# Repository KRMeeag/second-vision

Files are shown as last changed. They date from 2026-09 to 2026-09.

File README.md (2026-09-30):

# **Second Vision: IoT-Based Smart Glasses for the Visually Impaired**

Real-time object detection and depth estimation on edge hardware, delivering spatial awareness through audio and haptic feedback.

---

## What It Does

Second Vision is a head-mounted assistive device that helps visually impaired users navigate their surroundings:

- **🔊 Audio Feedback** — Announces detected objects with spatial position: *"person left"*, *"car center"*, *"bicycle right"*
- **📳 Haptic Feedback** — Three vibration motors (left, center, right) vibrate proportionally to obstacle proximity
- **🧭 Body- and Head-Height Awareness** — Second Vision watches for the things people walk into: walls, doors, furniture, other people, low branches and overhanging signs at torso and head height. It does not sense the ground, so it will **not** warn about stairs, curbs or drop-offs — every wearer is told this before first use.

Object detection identifies *known* objects (people, cars, obstacles). Depth estimation detects *all* obstacles, including those the AI can't classify. 

---

## Hardware

| Component | Spec |
|---|---|
| Compute | Raspberry Pi 5 (8GB RAM) |
| AI Accelerator | Hailo AI Hat+ (Hailo-8, 26 TOPS) |
| Camera | OV2640 USB Camera Module |
| Motor Controller | ESP32 (wired USB serial) |
| Vibration Motors | 3× ERM (left temple, forehead, right temple) |
| Audio | Bone-conduction earphones |
| Control Panel | Arduino (switches, potentiometers, buttons) |
| Power (motors) | 18650 Li-ion cell via MOSFETs |
| OS | Raspberry Pi OS Trixie (64-bit) |

## Software Stack

| Layer | Technology |
|---|---|
| Detection Model | YOLOv8n (Hailo HEF) |
| Depth Model | SC-DepthV3 (Hailo HEF) |
| Inference Runtime | HailoRT + GStreamer |
| Framework | [`hailo_apps`](https://github.com/hailo-ai/hailo-apps) (pip-installed library) |
| TTS | pyttsx3 / espeak-ng |
| Serial Protocol | Binary (RPi5 ↔ ESP32), Text (Arduino → RPi5) |
| Language | Python 3.13 |

---

## Quick Start

### Prerequisites

- Raspberry Pi 5 with Hailo AI Hat+ installed
- `hailo_apps` package installed in virtual environment
- OV2640 camera connected via USB

### Setup

```bash
# Clone the repository
git clone <repo-url>
cd second-vision-repo

# (FOR RPI ONLY) Make sure to have the necessary PyGOBject and GStreamer bindings (required)
sudo apt install python3-gi python3-gi-cairo gir1.2-gtk-4.0

# Install necessary project dependencies
poetry install 

# Create and activate virtual environment
python3 -m venv --system-site-packages my_hailo_env
source my_hailo_env/bin/activate
```

### Run

```bash
# Mock mode (no hardware needed — for development)
./scripts/run.sh --mock

# With camera (display mode for testing)
./scripts/run.sh --input rawusb:///dev/video0 --width 640 --height 360 --frame-rate 25

# Full system (headless, with ESP32 and Arduino)
./scripts/run.sh --input rawusb:///dev/video0 --width 640 --height 360 --frame-rate 25 \
    --serial-port /dev/ttyUSB0 \
    --config-port /dev/ttyACM0 \
    --headless
```

---

## Architecture

```
Camera → Hailo-8 NPU ─┬─→ YOLOv8n (detection) → TTS → Speaker
                       └─→ SC-DepthV3 (depth)  → ESP32 → 3× Motors

Arduino Control Panel → RPi5 → Runtime configuration
```

The system runs a GStreamer pipeline with two parallel inference branches. Each branch has a callback that pushes results into a thread-safe queue. Daemon worker threads consume from the queues and produce outputs (audio, serial commands).

See [`documentation/ARCHITECTURE.md`](documentation/ARCHITECTURE.md) for the full architecture document.

---

## Project Structure

```
second-vision-repo/
├── src/
│   └── second_vision/
│       ├── main.py                ← Entry point
│       ├── pipeline/              ← GStreamer pipeline + callbacks
│       ├── workers/               ← TTS, serial, config reader threads
│       ├── core/                  ← Config, protocol, depth utilities
│       └── mock/                  ← Fake data generators for --mock mode
├── scripts/
│   └── run.sh                     ← Launch script
├── config/                        ← Default settings
├── tests/                         ← Unit tests
├── documentation/                       ← Documentation
│   ├── PROJECT.md                 ← Project overview
│   ├── ARCHITECTURE.md            ← System architecture
│   ├── DECISIONS.md               ← Architectural decisions log
│   ├── PLAN.md                    ← Implementation phases
│   └── TASKS.md                   ← Task breakdown
├── CLAUDE.md                      ← AI agent instructions
└── README.md                      ← You are here

```

---

## Development

### Mock Mode

Run the full system without any hardware. Generates fake detections and depth data for testing workers:

```bash
./scripts/run.sh --mock
```

### Stub Pattern

Every component starts as a working stub. Replace the private functions marked `# STUBS BELOW` with real implementations. The worker loop, queue interface, and config integration never change.

See [`documentation/PLAN.md`](documentation/PLAN.md) for the phased implementation plan.

### Running Tests

```bash
source my_hailo_env/bin/activate
python3 -m pytest tests/
```

---

## Documentation

| Document | Description |
|---|---|
| [`AGENT.md`](AGENT.md) | Instructions for AI coding agents — read this first |
| [`PROJECT.md`](documentation/PROJECT.md) | Project overview, team, hardware specs |
| [`ARCHITECTURE.md`](documentation/ARCHITECTURE.md) | System architecture, data flow, protocols |
| [`DECISIONS.md`](documentation/DECISIONS.md) | All architectural decisions with rationale |
| [`PLAN.md`](documentation/PLAN.md) | 10-phase implementation plan |
| [`TASKS.md`](documentation/TASKS.md) | Granular task checklist |

---

## Researchers

- **Kenzhu Aguilera**
- **Waldric Jude S. Garcia**
- **Kenth Razen M. Magbanua**
- **Reiven O. Jasa**

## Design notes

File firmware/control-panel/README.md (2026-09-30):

# Second Vision — ESP32 Control Panel (PlatformIO)

Firmware for the physical settings panel. Emits the line protocol parsed by
`src/second_vision/workers/config_reader.py`:

    V:panel:<n>        protocol version, boot only
    S:<key>:<value>    setting   e.g. S:motor_strength:0.60
    M:<mode>           pipeline mode: detection | depth | both | none
    B:<name>           event: status | alive

`PROTOCOL.md` is the authoritative contract. Where this README and that file
disagree, PROTOCOL.md wins.

Wiring diagrams:

| File | Covers | Regenerate with |
|---|---|---|
| `docs/breadboard_wiring.svg` | controls → ESP32, on the breadboard | `python3 docs/gen_wiring.py` |
| `docs/pi_link_wiring.svg` | ESP32 → Raspberry Pi 5, over UART | `python3 docs/gen_pi_link.py` |

Edit the board constants at the top of `gen_wiring.py` before re-running it.

## Environments

| Env | File | Use |
|---|---|-----|
| `polarity` | `src/polarity_test.cpp`| Bring-up. Raw pin states + ADC + implied mode. |
| `panel` | `src/control_panel.cpp`| The real firmware. Default env. |
| `bench` | `src/control_panel.cpp`| Same firmware, `-D HAVE_POT=0`. For a bare board with no breadboard — an unfitted pot floats GPIO34 and floods the link. |

### The motor board lives elsewhere

Everything in `src/` is **control-panel** firmware. The glasses /
vibration-motor ESP32 (XIAO ESP32-C3, binary, 115200, bidirectional, driven
by `--serial-port` rather than `--config-port`) has its own PlatformIO
project in `firmware/esp32_haptic_feedback/`. The old `motorlink` link-check
sketch that used to sit here as `src/main.cpp` is gone; that board's
protocol is exercised by `scripts/test_motor_packet.py` and
`tests/test_serial_worker.py` instead.

`PROTOCOL.md` documents the **panel** protocol only.

    pio run -e polarity -t upload -t monitor
    pio run -e panel    -t upload -t monitor
    pio run -e bench    -t upload -t monitor    # laptop, no breadboard

Upload is 115200: this DevKit fails at both 921600 and 460800 once esptool
switches to the high rate for the stub. Hold IO0 for the ENTIRE upload — the
auto-reset is unreliable.

## Controls

Two latching rockers, one per capability. Each owns a model **and** the output
channel that model feeds — a model with no route to the user is just heat.

| Rocker | Model | Output channel |
|---|---|---|
| `DETECT` | YOLOv8 object detection| speech (`tts_enabled`) |
| `DEPTH`  | SC-DepthV3 depth | motors (`vibration_enabled`)|

The pair *is* the pipeline mode — there is no separate mode control, so the
panel can never show a position that is not what is running:

| DETECT | DEPTH | emitted |
|---|---|---|
| on | on | `M:both` |
| on | off | `M:detection` |
| off | on | `M:depth` |
| off | off | `M:none` |

`M:none` means **run nothing** — not "run both and mute". A model with no route
to the user is wasted Hailo time and battery. `app.py` has a matching
`MODE_NONE` with an idle pipeline builder that keeps the camera running but
detaches both inference branches, so flipping a rocker back is near-instant
rather than paying a camera cold-start on top of the rebuild blackout.

## Pin map

| Control | Pin | Notes |
|---|---|---|
| DETECT rocker  | GPIO17  | latching, INPUT_PULLUP, active LOW |
| DEPTH rocker | GPIO18  | latching, INPUT_PULLUP, active LOW |
| Status button  | GPIO22  | momentary, active LOW |
| B10K pot | GPIO34  | ADC1, input-only, no pull-up |

GPIO19 and GPIO21 are free — the mode button and KY-004 are gone. Both wrote
settings the rockers now own, and two controls writing one setting is how a
panel ends up lying about its state.

**GPIO23 carries the Pi link wire** (UART2 TX) and is not free.

**Both rocker pins are chosen so a mis-plugged jumper cannot short the supply.**
GPIO17 and GPIO18 have plain GPIOs on either side (GPIO5/GPIO16 and
GPIO19/GPIO5), so a wire one hole off reads wrong rather than drawing current.
GPIO23 takes no *switch*: it is one row from the GND pin, on a row carrying 3V3
on the opposite side of the board, so a one-hole slip is a dead short across the
regulator — a hot module and garbage on every pin at once. A single soldered
link wire is acceptable there; a switch leg, which can bridge two rows, is not.

## Shared power, and the heartbeat

Panel and Pi are powered together by the X1202, so they boot together and the
Pi is ~30 s from opening the port. A one-shot report at boot would be lost,
leaving `SystemConfig` disagreeing with switches the user can see and feel.

So `control_panel.cpp` emits `B:alive` and then re-announces its whole state
every `HEARTBEAT_MS` (10 s), forever. That survives the boot race, a dropped
byte, and any restart of `main.py` while the panel stays powered — the common
case in development.

This is only safe because `config_reader.py` acts on **changes**: an
unconditional reader would call `trigger_rebuild()` on every heartbeat and tear
the Hailo pipeline down every 10 seconds. If you ever touch either side, that
invariant is the one to preserve.

## Serial

9600 baud, to match `_open_config_port()` on the Pi. The ESP32's ROM boot log
is 115200, so a burst of garbage on reset is expected and harmless.

At runtime the panel reaches the Pi over the GPIO UART, not USB — USB is only
for flashing, because the GPIO UART has no DTR/RTS to drive the bootloader.
Three wires, `docs/pi_link_wiring.svg`:

    X1202 5V     ->  ESP32 5V pin               power (XH2.54 header)
    X1202 GND    ->  ESP32 GND                  also the Pi's ground
    ESP32 GPIO23 ->  Pi pin 21  (GPIO9, uart3-pi5 RX)   NOT pin 10

**The link is pin 21, not pin 10.** The primary UART (`/dev/serial0`, pins
6/8/10) belongs to the motor-controller ESP32-C3 — verified by reading that
port, which carries its ROM banner. The panel gets a second UART instead:
`dtoverlay=uart3-pi5` in `config.txt`, GPIO8/GPIO9 on pins 24/21. GPIO9 is also
SPI0 MISO, so it is free only while `dtparam=spi` stays off.

**And the ESP32 end is GPIO23, not GPIO1.** GPIO1 is UART0 TX — the USB serial — and the
ROM bootloader dumps its 115200 log there on every reset, which would land
straight in `config_reader.py`. GPIO23 is UART2: the Pi never sees that garbage,
and USB stays usable for flashing and monitoring at the same time.

Power comes from the Geekworm X1202 UPS, not the Pi's header. The ESP32's own
`3V3` pin still feeds the breadboard `+` rail — the X1202's 5 V goes to the 5V
pin and nowhere else, so the pot keeps a safe 3.3 V reference. Because the X1202
feeds the Pi, its GND and the Pi's GND are one node — grounding the ESP32 there
already references it to the Pi, so only the signal wire touches the 40-pin
header. Unplug the 5 V feed before flashing over USB.

**Pin name depends on the board.** The 38-pin DevKit used here labels its 5 V
input `5V`; 30-pin boards label the same pin `VIN`. They are the regulator
input either way — never the `3V3` pin, which bypasses the regulator and puts
5 V straight on the module.

The Pi's serial login console was removed from `cmdline.txt` and
`enable_uart=1` added to `config.txt`. `/dev/serial0` (→ `ttyAMA0`) is the
**motor** link; `dtoverlay=uart3-pi5` adds the panel's own UART on GPIO8/9.

Confirm the device name after rebooting — Pi 5 numbering is not Pi 4's:

    ls -l /dev/ttyAMA*

then run the pipeline with `--config-port /dev/ttyAMA<n>` for whichever node
`uart3-pi5` created. Do **not** assume it; the primary already moved from
`ttyAMA10` to `ttyAMA0` once across a reboot in this project.

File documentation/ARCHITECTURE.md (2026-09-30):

# ARCHITECTURE.md — System Architecture

> **Last synced: 2026-07-27.** Verified against source.
> This is the single source of truth for how the system is built.
>
> The depth post-processing section is deliberately kept high-level: that design is still
> moving. See [PLAN.md](PLAN.md#2-depth-estimation-callbacks).

---

## System Overview

```
┌─────────────────────────────────────────────────────────────────┐
│                     HEAD-MOUNTED UNIT                           │
│  [Camera]  [Motor L]  [Motor C]  [Motor R]  [Earpiece]         │
└──────┬────────┬──────────┬──────────┬───────────┬───────────────┘
       │        │          │          │           │
  USB  │   ┌────┴──────────┴──────────┴────┐     │ audio
       │   │          ESP32                 │     │
       │   │  3× MOSFET PWM + 18650 power  │     │
       │   └──────────────┬────────────────┘     │
       │             USB Serial                   │
       │                  │                       │
┌──────┴──────────────────┴───────────────────────┴───────────────┐
│                    RASPBERRY PI 5                                │
│                                                                 │
│  ┌──────────────────────────────────────────────────────────┐   │
│  │              GStreamer Pipeline (Hailo-8 NPU)             │   │
│  │                                                          │   │
│  │  Camera → tee ──→ SCDepthV3 ──→ depth_callback           │   │
│  │               └──→ YOLOv8n ──→ tracker ──→ det_callback  │   │
│  └──────────────────────────────────────────────────────────┘   │
│           │                              │                      │
│     serial_queue                   tts_queue                    │
│     (queue.Queue)                  (queue.Queue)                │
│           │                              │                      │
│  ┌────────▼────────┐          ┌──────────▼──────────┐          │
│  │  Serial Worker   │          │    TTS Worker        │          │
│  │  (daemon thread) │          │   (daemon thread)    │          │
│  │  binary protocol │          │   espeak-ng + cooldown│          │
│  └────────┬─────────┘          └──────────┬──────────┘          │
│           │                               │                     │
│      USB Serial                      espeak-ng                  │
│      to ESP32                        subprocess                 │
│                                                                 │
│  ┌──────────────────┐     ┌─────────────────┐                  │
│  │  Config Reader    │     │  SystemConfig    │                  │
│  │  (daemon thread)  │────→│  (thread-safe)   │                  │
│  │  Arduino serial   │     │  shared state    │                  │
│  └────────┬──────────┘     └────────┬────────┘                  │
│           │                         │ read by all workers       │
│      USB Serial                     │                           │
└───────────┼─────────────────────────┼───────────────────────────┘
            │                         
┌───────────┴──────────┐              
│   Arduino Control     │              
│   Panel (switches,    │              
│   pots, buttons)      │              
└──────────────────────┘              
```

---

## Threading Model

| # | Thread | Type | Input | Output | Lifetime |
|---|---|---|---|---|---|
| 1 | GLib MainLoop | Main thread | GStreamer bus events | Pipeline state mgmt | App lifetime |
| 2 | Depth streaming | GStreamer-managed | Camera frames | SCDepthV3 inference → depth_callback | While depth pipeline active |
| 3 | Det streaming | GStreamer-managed | Camera frames | YOLOv8 inference → det_callback | While det pipeline active |
| 4 | TTS Worker | `threading.Thread` daemon | `tts_queue` | espeak-ng audio | App lifetime |
| 5 | Serial Writer | `threading.Thread` daemon | `serial_queue` | Binary packets to ESP32 | App lifetime |
| 6 | Config Reader | `threading.Thread` daemon | Arduino serial text | `SystemConfig` updates | App lifetime |
| 7 | *(opt)* Watchdog | `threading.Thread` daemon | Frame count | Restart on stall | If `--enable-watchdog` |

The debug overlay is **not** a separate thread. It is drawn with cv2 inline inside the
detection callback, gated on `user_data.use_frame`. A separate composite debug window
(`--debug-display`) is a planned task, not current behaviour.

### Shutdown sequence

1. `SIGINT` (Ctrl+C) or pipeline error
2. `user_data.shutdown_event.set()`
3. All workers check `shutdown_event` in their `queue.get(timeout=1.0)` loop
4. Workers exit within ~1 second
5. `main()` joins threads with `timeout=2.0`
6. Process exits

---

## Data Flow Contracts

### Detection → TTS

`tts_queue` is a **`PriorityMailbox`**, not a `queue.Queue`. It exposes
`offer()` / `take()` / `peek()` — there is no `put_nowait` / `get`. It holds one slot and
keeps the **higher-priority** of {stored, incoming}, ties going to the newer item, so a
busy TTS worker receives the most urgent item rather than a stale one. `offer()` never
blocks and never raises.

```
GStreamer det_callback → user_data.tts_queue.offer({
    "label": "person",          # str: YOLO class label
    "zone": "left",             # str: "left" | "center" | "right"
    "confidence": 0.87,         # float: 0.0-1.0
    "priority": 2.45,           # float: composite score, higher = surface first
    "tier": "normal",           # str: "normal" | "urgent"
    "phrase": "person still left",   # str, OPTIONAL: overrides "{label} {zone}"
})

# Mode announcement (special):
user_data.tts_queue.offer({
    "announce": "detection mode"  # str: spoken as-is
})
```

Items arriving without `priority` / `tier` (mock data, mode announcements) are defaulted by
`item_priority()` / `item_tier()` in `core/priority.py`. Announcements get `+inf` priority
and urgent tier, so a physical mode switch is always heard.

### Depth → Serial

```
GStreamer depth_callback → user_data.serial_queue.put_nowait({
    "left": 200,                # int: 0-255 motor PWM intensity
    "center": 50,               # int: 0-255
    "right": 180,               # int: 0-255
    "hazard": False,            # bool: ground hazard detected?
    "hazard_severity": 0,       # int: 0-255
})
```

### Arduino → Config

```
Text protocol over serial (9600 baud):
  "S:motor_strength:0.75\n"    → config.update(motor_strength=0.75)
  "S:tts_enabled:0\n"          → config.update(tts_enabled=False)
  "M:detection\n"              → config.update(pipeline_mode="detection") + rebuild
  "B:announce_status\n"        → button event handler
```

---

## Binary Serial Protocol (RPi5 → ESP32)

### Packet format

```
| START (0xAA) | MSG_TYPE (1B) | PAYLOAD (N bytes) | CHECKSUM (1B) |
Checksum = XOR of all bytes from MSG_TYPE through end of PAYLOAD
```

### Message types

| Direction | Type | Code | Payload | Total bytes |
|---|---|---|---|---|
| RPi → ESP32 | MOTOR_UPDATE | `0x01` | `left(1B) center(1B) right(1B)` | 6 |
| RPi → ESP32 | HAZARD_ALERT | `0x04` | `severity(1B) pattern(1B)` | 5 |
| RPi → ESP32 | HEARTBEAT | `0xFE` | none | 3 |
| ESP32 → RPi | ACK | `0xFF` | `acked_type(1B)` | 4 |

### Wire config

```
Baud:     115200
Data:     8 bits
Stop:     1 bit
Parity:   None
Flow:     None
```

---

## Pipeline Modes

The system supports four pipeline configurations, switchable at runtime via the ESP32 control panel. The mode is not a setting the panel sends independently — it is derived from the positions of the two latching rockers, so the panel can never display a state that is not running.

| Mode | GStreamer Pipeline | Active Callbacks | Use Case |
|---|---|---|---|
| `"both"` | Source → tee → (SCDepthV3 + YOLOv8) | Both | Default — full system |
| `"detection"` | Source → YOLOv8 → tracker | det_callback only | Familiar routes, TTS only |
| `"depth"` | Source → SCDepthV3 | depth_callback only | Open areas, haptics only |
| `"none"` | Source → fakesink (no inference) | frame counter only | Both rockers off — run nothing |

`"none"` keeps the camera running on purpose. Tearing the source down would save a little idle power, but returning would cost a camera cold-start on top of the rebuild blackout in D21, and a rocker is exactly the control a user flips straight back. A callback identity stays wired with its handler disabled so the frame counter keeps moving — otherwise `--enable-watchdog` reads idle as a stall.

Switching is done via `GLib.idle_add(app._rebuild_pipeline)`. The ~0.8-1.2s blackout during rebuild is masked by a TTS announcement ("detection mode").

---

## Depth Processing

### Zone splitting (25/50/25)

```
Frame width:
  ├── 0-25% ──┤── 25-75% ──────────────┤── 75-100% ──┤
     LEFT           CENTER                   RIGHT
   (Motor L)       (Motor C)               (Motor R)
```

Stable: the frame is split L/C/R with a wider centre, each zone producing one 0–255 intensity for the `serial_queue` contract. Closer must map to stronger along a non-linear curve — linear feels unnatural to users.

### Units — relative, not metres

The SC-DepthV3 postprocess `.so` emits **relative model units**, not metres. Any constant carrying an `_M` suffix in prototype code is still in those relative units despite the name. Porting metric-looking thresholds without preserving that semantics produces plausible but wrong motor output — a silent failure on an assistive device, which is worse than a loud one.

### Edge cases the design must handle

These come from the requirements, so they outlive any particular algorithm:

| Edge case | Why raw depth is not enough |
|---|---|
| Thin objects (poles, cables, chair legs) | Networks smooth them away; a whole-zone aggregate averages them out |
| Blank / textureless walls | No texture → scale ambiguity → washed-out, uncertain output |
| Near walls the model renders as *far* | Same ambiguity, but failing dangerously rather than noisily |
| Drop-offs and descending stairs | A drop reads as "far", indistinguishable from open space — *stair / drop-off / step-up detection is OUT OF SCOPE (D36). The ground plane itself is still modelled (floor suppression) and obstacles standing on it are still detected* |
| The floor itself | A forehead camera angled down sees the wearer's own feet in every frame — the *nearest* surface the model reports, and every "how near is this?" detector fires on it |

### The floor is not an obstacle

Measured on the real chain (`depth_utils.py`, Sept 2026) with a synthetic open floor: an **empty** scene drove all three zones to ~213/255 and the motors to 145/145/145; a person at collision range fully inside the right zone changed the motors by nothing — the floor set the level in every zone, and the contrast + quantize stages collapsed the remaining gap. That is the "person on the right, centre rings" field report.

`depth_utils.floor_profile` fits `1/depth = a + b·row` (a plane under a pinhole camera) to the row medians of the bottom `FLOOR_FIT_FRACTION` of the grid, extrapolates it upward, and `suppress_floor` erases every pixel at or beyond that plane before the near-cluster and blank-wall detectors run. The fit is **refused** unless the plane recedes by `FLOOR_MIN_RECESSION` across the window, so a wall filling the bottom of the frame is never mistaken for a floor; rows above the horizon keep everything. `detect_floor_to_wall` and `detect_ground_hazard` still read the raw grid — they need the floor as their ruler. `FLOOR_SUPPRESSION = False` restores the previous behaviour in one line. The HUD darkens erased pixels.

### Direction has to be amplified, not preserved

`haptics.py` runs **winner-take-most** after lateral contrast: each zone is pushed down by `WINNER_SUPPRESSION` × its shortfall from the loudest zone. Tied zones (a wall across the field, a corridor's two walls) pass through unchanged; a zone that is merely trailing is silenced. With three motors the only direction the device can express is *which zone wins*, and a 255-vs-200 pair that lands on the same quantizer level says nothing.

### Current state in this repo

`_process_real_depth` in `pipeline/callbacks.py` runs the full chain above (`DepthPostProcessor` → `HapticMapper` → `serial_queue`).

**Ground-hazard detection is disabled** (`GROUND_HAZARD_ENABLED = False`, DECISIONS D36): the callback publishes `hazard=False, hazard_severity=0` on every frame *on purpose*: the detector was not trustworthy enough to ship, and the wearer must be told the device does not see stairs (there is no cane fallback — D16). `detect_ground_hazard` / `HazardDebouncer` remain in `depth_utils.py`, tested, and the serial contract keeps both fields, so the firmware's `HAZARD_ALERT` path is unchanged and simply never triggered.

**Open interface question (parked with the feature):** the detector distinguishes a drop-off (`"down"`) from a step-up/curb (`"up"`), but the `serial_queue` contract has no field for direction and `HAZARD_ALERT`'s payload is severity + pattern. Settle it only if the feature is re-enabled.

---

## TTS Prioritization and Suppression

> The per-`"{label}-{zone}"` `CooldownManager` this section used to describe **no longer
> exists** — it was deleted in the priority revamp. Suppression now lives in one layer
> (callback + `core/priority.py`), not two competing ones.

### Choosing what to say

Every qualifying detection gets a composite **priority** score — confidence + bbox area +
zone weight + class weight, minus a decaying recency penalty — and an urgency **tier**
(`normal` / `urgent`). One winner per frame is chosen by priority and offered to the
mailbox. Nothing is lost by reducing to one: persistent objects re-emit every frame from
`track_history`, so a runner-up simply wins on a later frame.

### Three layers of suppression

| Layer | Mechanism | Urgent bypasses? |
|---|---|---|
| Hard repeat floor | `MIN_REPEAT_INTERVAL` (10 s) between repeat announcements for a track | **Yes** |
| Soft recency penalty | Just-spoken items lose priority, decaying back over `RECENCY_DECAY_SECONDS` | No — it is a ranking term, not a gate |
| Inter-utterance gap | `MIN_UTTERANCE_GAP` (0.5 s) of silence after each utterance | **Yes** |

**Urgent deliberately bypasses both the floor and the gap.** An approaching car in the
centre must be able to re-announce and cut in even if that object spoke moments ago. If you
find a gate muting an urgent escalation, the gate is the bug — the bypass is intended.

### Preemption

While speaking, the worker polls the mailbox every ~50 ms. A pending item preempts if it is
urgent-tier **or** beats the current item's priority by more than `PREEMPT_MARGIN`. The
`PREEMPT_USE_TIER` flag flips this to pure relative-margin; both paths are kept live for
on-device A/B comparison.

All tunables live in `core/priority.py`, plus the detection-side constants in
`pipeline/callbacks.py`. See [FIELD-TESTING.md](FIELD-TESTING.md) for the symptom → parameter
tuning map.

### Zone boundary hysteresis

To prevent jitter when objects sit at zone boundaries:

```
Enter left:    center_x < 0.22
Enter center:  center_x > 0.25 AND center_x < 0.75
Enter right:   center_x > 0.78
Hysteresis:    0.22-0.25 and 0.75-0.78 = keep previous zone
```

The hysteresis bands **hold the previous zone** rather than dropping the detection, and the
state is tracked per tracker ID, not per label.

---

## ESP32 Safety

| Feature | Behavior |
|---|---|
| Watchdog | If no packet received for 3 seconds, set all motors to 0 |
| ACK | Send immediately upon parsing valid packet |
| Hazard pattern | Override normal motor values with pulsing pattern |
| Flyback diodes | 1N4148 across each motor (cathode to positive) |
| Power | 18650 → parallel motor wiring → individual MOSFETs per motor |

---

## File Map

```
src/second_vision/
├── main.py                 ← Orchestrator: creates config, starts workers, runs pipeline
├── main2.py                ← Temporary smoke-test script (deletion pending — see TASKS.md)
├── pipeline/
│   ├── app.py              ← SecondVisionApp: extends GStreamerApp (NOT GStreamerParallelApp)
│   ├── callbacks.py        ← on_det_frame (built), on_depth_frame (placeholder)
│   └── TBR-*.py            ← Draft/staging files, unwired. Not imported by anything
├── workers/
│   ├── tts_worker.py       ← espeak-ng, serialized + interruptible
│   ├── serial_worker.py    ← packet packing built; serial I/O still stubbed
│   └── config_reader.py    ← text protocol parsing built; serial I/O still stubbed
├── core/
│   ├── config.py           ← SystemConfig: thread-safe shared state
│   ├── priority.py         ← PriorityMailbox + all TTS scoring/preemption tunables
│   ├── protocol.py         ← PLANNED — packing currently lives in serial_worker.py
│   └── depth_utils.py      ← Placeholder; real approach still in the prototyping repo
└── mock/
    └── data_generator.py   ← fake detections + depth for --mock mode

tests/
└── test_priority.py        ← 19 tests: mailbox, scoring, tiers, preemption, worker
```

`SecondVisionApp` extends **`GStreamerApp`**. `GStreamerParallelApp` exists only in the
prototyping repo and is **not importable** from the installed `hailo_apps` library, so the
dual-branch pipeline is built inline here.

---

## Shared files — expect concurrent edits

Five workstreams run in parallel and legitimately touch the same files. This map exists so
you know *who else is in here*, so you can coordinate before and after a change.

**This is not an ownership gate.** Any member's agent may edit any of these files; the team
coordinates directly on what lands and how it affects the other side.

| File | Workstreams that touch it |
|---|---|
| `pipeline/callbacks.py` | depth (`_process_real_depth`), detection (`_process_real_detections`), TTS (tuning constants) |
| `pipeline/app.py` | control (`get_pipeline_string`, `_connect_callback`), depth (branch wiring), detection (tracker params) |
| `core/config.py`, `workers/config_reader.py` | control |
| `workers/serial_worker.py`, `core/protocol.py` | firmware, depth (hazard fields) |
| `core/priority.py` | TTS |
| `main.py` | all — worker startup and `user_data` construction |

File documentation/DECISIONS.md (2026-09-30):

# DECISIONS.md — Architectural Decision Log

> **Last synced: 2026-07-27.**
> D1–D29 come from the original architecture planning phase (v1–v8). D30+ were made during
> implementation and are promoted here from the `.agents/` handoffs.
>
> **Decisions are never silently rewritten.** When one is overtaken, it is marked
> *superseded* or *amended* and left in place, so the reasoning trail survives.

---

## Decision Index

| # | Decision | Choice | Rationale Summary |
|---|---|---|---|
| 1 | Consumer threading model | `threading.Thread` + `queue.Queue` | I/O-bound consumers; GIL irrelevant for serial/TTS |
| 2 | TTS engine | pyttsx3 / espeak-ng | < 1% CPU, < 50ms latency; utterances too short for neural TTS quality to matter |
| 3 | Serial protocol (ESP32) | Binary: `0xAA` + type + payload + XOR | Deterministic parsing on MCU, no string allocation |
| 4 | Baud rate | 115,200 | < 1% wire capacity used; universally reliable |
| 5 | ACK strategy | Non-blocking, 10ms timeout | Stale data worse than missing data in obstacle avoidance |
| 6 | Display mode | `--headless` flag → `fakesink` | Callbacks still fire regardless of sink; saves CPU/power |
| 7 | Depth zone split | 25% / 50% / 25% (L/C/R) | Center zone wider — forward obstacles matter most |
| 8 | Motor controller | ESP32 via wired USB serial | Reliable, no BLE latency, supports high baud rates |
| 9 | Motor wiring | Parallel + individual MOSFETs | Series wiring prevents independent motor control |
| 10 | ~~Cooldown strategy~~ | ~~Per `"{label}-{zone}"` key, 3s default~~ | **SUPERSEDED by D30–D34** — replaced by layered suppression |
| 11 | TTS scope | Detection only — no depth in speech | Prevents info overload; motors handle depth |
| 12 | Motor mode | Proportional (all motors active) | Single-motor mode has dangerous corridor failure mode |
| 13 | TTS phrasing | Short: `"person left"` | 0.6s per utterance; leaves silence between cooldowns |
| 14 | ESP32 firmware | Teammate-owned; protocol spec provided | Independent development against the binary protocol spec |
| 15 | Form factor | Head-mounted | Camera, motors, earpiece all on headband |
| 16 | Target user | Visually impaired, **no white cane** | Earlier drafts assumed a cane fallback; corrected Sept 2026 — see D36 |
| 17 | ~~Downward hazards~~ | ~~Software ground-plane departure detection~~ | **SUPERSEDED by D36** — disabled; not reliable enough to trust, and there is no cane fallback |
| 18 | Control panel protocol | Text: `"S:key:value\n"` | Human-speed input; debuggable with serial monitor |
| 19 | Config sharing | `SystemConfig` with `threading.Lock` | Workers poll on each loop iteration (< 1s latency) |
| 20 | Pipeline switching | Dynamic rebuild via `_rebuild_pipeline()` | **Reaffirmed 2026-07-27** — being built now alongside the control panel |
| 21 | Rebuild blackout | ~0.8-1.2s, masked by TTS announcement | ESP32 watchdog holds last motor values during gap |
| 22 | Thread count | 6 core + 2 optional, all daemon | Single `shutdown_event` for clean exit |
| 23 | Project structure | `src/second_vision/` imports `hailo_apps` as library | Never modify library; extend by subclassing |
| 24 | Entry point | `main.py` starts workers, then `app.run()` (blocking) | Workers must start BEFORE the blocking GLib loop |
| 25 | Dev approach | Walking skeleton with stubs | Full system runs end-to-end from day 1 |
| 26 | Mock mode | `--mock` flag with fake data generators | Enables development without RPi5/Hailo/camera |
| 27 | Stub pattern | Private `_functions` under `# STUBS BELOW` | Replace internals, never change the interface |
| 28 | Interface contract | Queue dict keys are the API | **AMENDED by D30** — keys and queue type both changed |
| 29 | Directly implemented | `SystemConfig`, `protocol.py`, mock generators | Simple enough to implement fully from start |
| 30 | TTS queue type | `PriorityMailbox`, keep-highest | A 1-slot `Queue` dropped the *newer* item — the opposite of the intent |
| 31 | Announcement selection | Composite priority score | Confidence/area alone can't tell "approaching car" from "routine reminder" |
| 32 | Urgency model | Two tiers: `normal` / `urgent` | Some events must be able to bypass every gate |
| 33 | Preemption | Urgent-tier OR relative margin | Barge-in for what matters; margin avoids twitchiness on near-ties |
| 34 | Suppression layering | Hard floor + soft penalty + pacing gap | One authority instead of two competing cooldowns |
| 35 | False-positive gate | `MIN_CONFIRMATION_SECONDS = 0.3` (seconds, not frames) | Gates the TTS label only; one-time cost per track |
| 36 | "multiple X" composition | Compose with **all** phrase types | Restricting it to first sightings made it fire at most once ever |
| 37 | Zone boundaries | `0.22 / 0.25 / 0.75 / 0.78`, hold-previous | Hysteresis holds the previous zone rather than dropping the detection |
| 38 | Depth development location | Prototyping repo first, then port | Depth needs rapid iteration against live captures |

---

## Detailed Rationale

### D1: Threads over Processes

**Alternatives considered**: `multiprocessing.Process`, `concurrent.futures.ThreadPoolExecutor`, `asyncio`

**Why threads win**:
- Consumers (TTS, serial) are **I/O-bound** — the GIL is released during espeak-ng subprocess calls and `serial.write()` system calls
- GStreamer callbacks already run in GLib-managed threads — adding worker threads fits naturally
- `multiprocessing` adds serialization overhead, sentinel patterns, potential deadlocks on `multiprocessing.Queue`
- `ThreadPoolExecutor` is designed for discrete tasks with `Future` results, not long-running consumer loops
- `asyncio` conflicts with GLib's own main loop

### D2: pyttsx3/espeak-ng over Piper TTS

**Alternatives considered**: Piper TTS (neural, ONNX-based), Google TTS (cloud)

**Why espeak wins**:
- Utterances are 3-5 words ("person left") — neural quality is imperceptible at this length
- espeak-ng: < 1% CPU spike, < 50ms latency
- Piper: 15-30% CPU spike, 200-500ms latency, 50-150MB model in RAM
- The device is already running two CV models on the Hailo NPU — CPU budget is tight
- Piper's `TextToSpeechProcessor` in the hailo_apps repo is designed for GenAI voice assistants (Hailo-10H), not pipeline detection announcements

### D9: Parallel Motor Wiring (Critical)

**The series mistake**: If motors are wired in series, opening any transistor breaks the entire circuit — all motors stop. You physically cannot control them independently. PWM on one motor affects current through all three.

**The fix**: Each motor has its own N-channel MOSFET. All motors share the 18650 power rail in parallel. Each MOSFET gate is driven by a separate ESP32 PWM pin. Flyback diodes (1N4148) across each motor protect against back-EMF spikes.

### D12: Proportional Motor Mode over Single-Motor

**The corridor problem**: If only the highest-proximity motor vibrates, the user walking between two walls feels vibration on one side only. They drift toward the "silent" side and hit the other wall.

**Proportional mode**: All three motors vibrate based on their zone's proximity. The user's brain naturally performs relative comparison — "both sides are buzzing, center is quiet" means "stay centered."

### D17: Software Downward Hazard Detection

**The limitation**: Monocular depth estimation (SC-DepthV3) reads stairs going down as "far" — the floor drops away, and depth increases. This looks like open space, not danger.

**The workaround**: Ground plane departure detection. The bottom 20-30% of the depth map shows ground 1-3m ahead. On flat ground, the depth gradient is smooth. A staircase creates a sudden gradient spike (depth jumps from "close ground" to "far nothing"). Detecting this spike ratio (> 5x median gradient) flags potential drop-offs.

**Limitations**: Works for staircases (3+ steps) and ledges. Small curbs and potholes may be below the noise floor.

**Superseded by D36.**

### D36: Ground-Hazard Detection Disabled (Sept 2026)

**Decision**: `GROUND_HAZARD_ENABLED = False` in `depth_utils.py`. The detector, its debouncer and its tests stay in the tree; the callback publishes `hazard=False, hazard_severity=0` on every frame, so the serial contract and the ESP32 firmware are untouched.

**Why**: the detector was the least trustworthy stage in the chain — D17's own limitation (a drop-off reads as "far") was never solved, the gate divides by the ground strip's noise and flapped 131 times in 400 frames on a static scene, and every threshold is an uncalibrated placeholder. A ground warning that is wrong that often teaches the wearer to ignore the device, which costs them the warnings that do work — and a device that *claims* to see stairs while missing most of them is more dangerous than one that is known not to.

**What it costs — read this**: the wearer uses **no white cane** (D16, corrected). With this off, **breaks in the ground are invisible to the device**: stairs, drop-offs, step-ups, curbs. Scoped precisely (team, 2026-09-15): it is the *hazard* detector that is out — the ground plane is still modelled every frame (`floor_profile`, DECISIONS on floor suppression) and obstacles standing on the floor are still detected. This was first recorded on the false premise that a cane covered them; it was re-confirmed by the team on 2026-09-12 knowing there is no fallback. **What it must not cost**: honesty — every user, demo, doc and script must state plainly that the device does not warn about stairs.

**To reverse**: calibrate `HAZARD_MIN_STEP` / `HAZARD_MAX_JUMP` against real stairs (`SV_CALIBRATE=1`, `core/calibration.py`), settle the direction question (D17 / TASKS), then flip the flag.

### D20: Dynamic Pipeline Rebuild over "Ignore Output"

**Alternative**: Keep both pipelines always running, just `if not enabled: return` in callbacks.

**Why rebuild wins for this device**:
- Head-mounted = user wears the heat source — thermal matters
- Battery-powered = power draw matters
- Mode switches are infrequent (physical toggle, not per-frame)
- ~1s blackout during rebuild is acceptable and masked by TTS announcement
- The framework's `_rebuild_pipeline()` already handles the full teardown/rebuild cycle

**Status 2026-07-27**: reaffirmed. `trigger_rebuild()` already defers correctly through
`GLib.idle_add`; the mode-aware pipeline builders are being written now alongside the
control panel.

---

# Implementation-phase decisions (D30+)

> Promoted from `.agents/handoff_v2.md` and `.agents/handoff_v3.md` so they are visible to
> the whole team rather than living only in local handoff notes.

## D30: `PriorityMailbox` replaces `queue.Queue(maxsize=1)`

**The bug in the old design**: a 1-slot queue with `put_nowait` + drop-on-`Full` drops the
**newer** event and keeps the **older** one — exactly backwards from the "avoid stale
phrases" intent that motivated `maxsize=1` in the first place.

**The replacement**: one slot, but `offer()` keeps the higher-priority of {stored, incoming},
ties going to the newer item. Never blocks, never raises, backlog cannot accumulate.

**Contract change (amends D28)**: `tts_queue` exposes `offer` / `take` / `peek` — not
`put_nowait` / `get`. The detection dict gained `priority` (float) and `tier`
(`"normal"` | `"urgent"`), plus an optional `phrase` override. Items without those fields are
defaulted, so mock and announcement paths keep working; announcements get `+inf` priority and
urgent tier so a physical mode switch is always heard.

## D31: Composite priority score

`confidence + area + zone_weight + class_weight − recency_penalty`, all terms normalized to
roughly 0–1 with equal starting weights so they stay comparable.

Previously the frame's winner was `max(confidence, area)`, which cannot distinguish a
fast-approaching car from a routine "still there" reminder — only which was detected more
confidently or looked bigger.

`W_APPROACH` is a **reserved hook at 0.0** for approach velocity. Wiring it means storing
`prev_area` on the existing `track_history` entry and computing `(area − prev_area)/dt` — no
restructuring needed. Deliberately not computed yet.

Class and zone weights are **placeholders**, not committed policy: the final detection class
set isn't settled, so they ship as an easily-edited table.

## D32–D33: Tiers and preemption

An item is urgent if it is a vehicle-type class in the centre zone, or if its absolute
priority crosses `URGENT_ABS_THRESHOLD`. `preempts(new, current)` returns true if the new
item is urgent-tier **or** beats the current one by more than `PREEMPT_MARGIN`.

`PREEMPT_USE_TIER` flips this to pure relative-margin. **Both paths are kept alive
deliberately** — the intent is to A/B them on-device, so don't hardcode one.

## D34: Layered suppression, one authority

Two independent cooldowns used to coexist: a per-track one in `callbacks.py` and a separate
`CooldownManager` keyed by `(label, zone)` in `tts_worker.py`. Both had to independently
agree before anything was spoken.

Resolution — the worker's `CooldownManager` was **deleted**, and suppression became three
cooperating layers with distinct jobs:

- **Hard floor** (`MIN_REPEAT_INTERVAL`) — an *eligibility gate*
- **Soft recency penalty** — a *ranking term* among the eligible
- **Pacing gap** (`MIN_UTTERANCE_GAP`) — *calm cadence* between utterances

**Urgent bypasses the hard floor and the pacing gap.** This is intended, not an oversight: an
approaching car in the centre must be allowed to re-announce and to cut in. A gate muting an
urgent escalation is the bug.

## D35: Confirmation gate in seconds, not frames

A track must exist for `MIN_CONFIRMATION_SECONDS = 0.3` before its first announcement,
filtering 1–2 frame tracker/NMS glitches.

**Why seconds**: it gates only the TTS *label*, not the haptic/hazard channel (separate per
D11/D12); it is a one-time cost per track, not recurring; and 0.3 s is roughly 3× the
tracker's own `keep_new_frames` grace period at the assumed 30 fps operating point.

Requires a `first_seen` field that — unlike `zone_since` — **does not reset on a zone
change**, so an object walking centre → left isn't re-treated as new.

## D36: "multiple X" composes with all phrase types

**The rule**: multiplicity is checked *before* the event phrase, and composes with it —
`"multiple person center"`, `"multiple person still center"`, `"multiple person leaving to
left"`. Originally the opposite ("say multiple only when there is no event phrase"), then
**explicitly reversed** after live testing.

**Why the original failed** — not because an event phrase is rare, but because of which case
dominates at runtime. `phrase` is `None` for a brand-new track, for a track that hasn't
announced yet, for a zone change that isn't centre→side, and when head-turn suppression
fires. But for the case that actually matters — a group standing together in one zone — the
first announcement has no phrase and **every repeat after it is a `"still X"` phrase**. So
the old rule said "multiple" once and reverted to singular for the rest of the episode. A
technically-correct rule producing a near-useless result.

**Lesson worth keeping**: when a rule says "only in case X, never in case Y", work out what
fraction of real runtime falls into X before treating the design as settled.

**Separate fix, same feature**: the group tally is built from `track_history` *after* stale
cleanup and counts only tracks past `MIN_CONFIRMATION_SECONDS` — not the current frame's raw
detections. A single frame where the detector blinks therefore cannot undercount a group that
is genuinely still present.

Wording stays literal (`"multiple person center"`). Pluralization is **deferred, not
rejected** — it waits on the final class list.

## D38: Depth is developed in the prototyping repo, then ported

Depth post-processing needs fast iteration against live captures and off-device replay
tooling, which the prototyping repo already has. This repo receives it as a **port**:
integration, imports, coexistence with the haptic path, and coding standards — not algorithm
development.

**Consequence to be aware of**: two `depth_utils.py` exist, and their constants look
interchangeable but are not (relative model units vs metric). See ARCHITECTURE.md.

**Open, not decided here**: the prototype's depth debug view uses `multiprocessing`, which
sits in tension with **D1** (threads over processes). The production math is cheap
vectorized NumPy and is safe in-thread; the tension is only about the debug visualization
path. The depth owner should make this call explicitly during the port rather than defaulting
either way.

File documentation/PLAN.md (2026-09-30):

# PLAN.md — Development Plan

> **Last synced: 2026-07-27.** Verified against source, not against prior documents.
> This is the shared plan for the whole team. Each workstream below runs **concurrently**,
> driven by a different member. Read your own section; read the others before touching a
> file they own.

Superseded model: this document used to describe ten sequential phases. The team never
worked that way — five workstreams progress in parallel — so the phase numbering is gone.
If you find a "Phase N" reference in an old document, map it here by name.

---

## Workstreams at a glance

| Workstream | Role label | State |
|---|---|---|
| [Object detection callbacks](#1-object-detection-callbacks) | detection owner | Substantially built; recent fixes not yet validated on hardware |
| [Depth estimation callbacks](#2-depth-estimation-callbacks) | depth owner | Placeholder here; **approach under active design** in the prototyping repo |
| [TTS](#3-tts) | TTS owner | Built, including the priority/preemption revamp. Tuning deferred to last |
| [ESP32 vibration motors](#4-esp32-vibration-motors) | firmware owner | ESP32 side done; **RPi side unimplemented**; UART comms in progress |
| [Control panel + mode switching](#5-control-panel--mode-switching) | control owner | Reader stubbed, mode-awareness unimplemented; hardware in progress |

**Field testing and TTS tuning happen last**, after the four build streams converge — see
the [Field testing gate](#field-testing-gate).

---

## 1. Object detection callbacks

**Role label:** detection owner
**Purpose:** Turn YOLO detections into a single, well-chosen spoken event per frame.

### Built and working

Implemented in `_process_real_detections` ([`pipeline/callbacks.py`](../src/second_vision/pipeline/callbacks.py)):

- **Zone assignment with hysteresis** — boundaries `0.22 / 0.25 / 0.75 / 0.78`. A detection
  sitting in a boundary band **keeps its previous zone** rather than being dropped, so an
  object loitering on a zone line doesn't flip-flop.
- **Confirmation gate** — `MIN_CONFIRMATION_SECONDS = 0.3`. A track must exist this long
  before its first announcement, filtering 1–2 frame tracker/NMS glitches. Backed by a
  `first_seen` field that, unlike `zone_since`, survives zone changes.
- **Stale-track cleanup** — `STALE_TRACK_FRAMES = 15`. Runs on empty frames too, so an
  object leaving abruptly doesn't leave its state behind.
- **Head-turn suppression** — when most tracked objects slide sideways together it reads as
  a camera pan, suppressing "leaving to X" for `HEAD_TURN_SUPPRESS_SECONDS`. Requires
  `HEAD_TURN_MIN_TRACKED = 3` so a lone object can't suppress its own transition.
- **"multiple X" wording** — group size is tallied from `track_history` *after* stale
  cleanup, not from the current frame's raw detections, so one flickered frame can't
  undercount. Composes with all phrase types (`still X`, `leaving to X`), not just first
  sightings.
- **Priority + tier per detection**, one winner per frame, offered to the TTS mailbox.
- **cv2 debug overlay** — zone tints, divider lines, per-object boxes and IDs, FPS. Gated
  on `user_data.use_frame`.

### Next

- Validate the confirmation gate, "multiple X" composition, and the flicker-tolerant tally
  **on real hardware**. All three were verified only against mocked-hailo harnesses.
- Decide whether `CONFIDENCE_THRESHOLD` (0.70) and the NMS thresholds in `app.py` need
  tuning to cut false positives at the source. Additive to the confirmation gate, not a
  replacement.
- Settle the final detection class list. Pluralization (`person` → `people`) is deferred
  until then and does not exist anywhere yet.

### Key files

`pipeline/callbacks.py`, `pipeline/app.py` (tracker parameters).

---

## 2. Depth estimation callbacks

**Role label:** depth owner
**Purpose:** Turn the raw depth map into left/center/right warning intensities for the
haptic channel.

### Status: in flux — deliberately not pinned down here

The depth post-processing approach is **being actively designed right now** in the
prototyping repo, and it is changing rapidly. An early mean-per-zone approach was already
abandoned as far too simplistic. **This document does not describe the current algorithm on
purpose** — anything written at that level of detail would be stale within days.

**Go to the prototyping repo for current detail:**
`/home/sv-rpi5/Projects/Test-Projects/ai-test/hailo-apps/hailo_apps/python/pipeline_apps/custom_depth_detection/`
(plus `SV-Docu/depth_backlog.md` and `SV-Docu/depth_estimation_handoff.md`).

### What is stable enough to write down

**The edge cases the design must handle** — these come from the requirements, not the
implementation, so they outlive any given algorithm:

| Edge case | Why depth alone fails |
|---|---|
| Thin objects (poles, cables, chair legs) | Networks smooth them away; a whole-zone aggregate averages them out |
| Blank / textureless walls | No texture → scale ambiguity → washed-out, uncertain output |
| Near walls the model renders as *far* | Same ambiguity, but failing dangerously rather than noisily |
| Drop-offs and descending stairs | A drop reads as "far", i.e. indistinguishable from open space — *stair / drop-off / step-up detection is OUT OF SCOPE (D36). The ground plane itself is still modelled and obstacles on it are still detected* |

**In this repo today:** `_process_real_depth` in
[`pipeline/callbacks.py`](../src/second_vision/pipeline/callbacks.py) runs the real chain
(`core/depth_utils.py` → `core/haptics.py` → `serial_queue`). It emits `hazard=False` on every
frame **by decision** (DECISIONS D36): ground-hazard detection is disabled as unreliable, and
the fields stay only to keep the ESP32 contract intact.

**Units:** the SC-DepthV3 postprocess emits **relative** model units, not metres. Any
constant carrying an `_M` suffix in prototype code is still in those relative units.

### Next

1. Continue the design/validation loop in the prototyping repo.
2. Port into this repo. The port is **integration work, not algorithm development**: verify
   how to import it here, make it coexist with the haptic path, and apply this repo's coding
   standards before it lands.
3. Tune parameters against real captures.

> **Documentation gate.** Once the depth callbacks are ported with proper test cases and the
> user is satisfied with them, **updating these docs is the immediate next task** — this
> section, ARCHITECTURE.md's depth section, TASKS.md status, and any decision the port
> settled. The moment the approach stops moving is the moment it becomes worth writing down.

### Key files

`pipeline/callbacks.py` (`_process_real_depth`), `core/depth_utils.py` (placeholder).

---

## 3. TTS

**Role label:** TTS owner
**Purpose:** Speak the most important thing, one utterance at a time, without overwhelming
the user.

### Built and working

- **Serialized, interruptible speech** ([`workers/tts_worker.py`](../src/second_vision/workers/tts_worker.py)) —
  one espeak-ng subprocess at a time, watched to completion. A ~50 ms poll while speaking
  lets an urgent or decisively higher-priority item terminate the current utterance and take
  over. This fixed the layering bug where announcements spoke over each other.
- **`PriorityMailbox`** ([`core/priority.py`](../src/second_vision/core/priority.py)) —
  single slot that keeps the **higher-priority** of {stored, incoming}, ties to the newer
  item. Replaced `queue.Queue(maxsize=1)`, whose drop-on-full policy kept the *stale* item.
- **Composite priority score** — confidence + bbox area + zone weight + class weight, minus
  a decaying recency penalty. An urgency **tier** (`normal` / `urgent`) rides alongside.
- **Layered suppression** — a hard repeat floor (`MIN_REPEAT_INTERVAL = 10.0 s`), a soft
  recency penalty folded into the score, and a minimum inter-utterance gap
  (`MIN_UTTERANCE_GAP = 0.5 s`). **Urgent bypasses both the floor and the gap** — this is
  deliberate, not a bug.
- **Every threshold is a named constant in one file** so it can be tuned by ear on-device.
- **19 unit tests** in `tests/test_priority.py`, including worker serialization and
  preemption against a fake espeak — no hardware needed.

### Next — but scheduled last

Field testing and by-ear tuning is the **final** activity for the project, after the other
workstreams converge. See the [Field testing gate](#field-testing-gate) and
[FIELD-TESTING.md](FIELD-TESTING.md).

Also open: `W_APPROACH` is a reserved hook sitting at `0.0`. Wiring approach velocity
(bbox-area growth per second, using the `prev_area` that `track_history` can already carry)
is the most likely next scoring improvement — field testing scenario U1 is designed to
produce the evidence for whether it's needed.

### Key files

`core/priority.py` (all tunables), `workers/tts_worker.py`, `tests/test_priority.py`.

---

## 4. ESP32 vibration motors

**Role label:** firmware owner
**Purpose:** Drive three vibration motors from depth intensities over USB serial.

### Built and working — ESP32 side

The board is built and its firmware logic is **done**: binary protocol parsing, checksum
validation, `MOTOR_UPDATE` → 3× PWM, `HAZARD_ALERT` → pulsing override, `HEARTBEAT` →
watchdog reset, ACK responses, and the 3-second watchdog that zeroes the motors.

### Not built — RPi side

**UART communication between the Pi and the ESP32 is still being built.** In
[`workers/serial_worker.py`](../src/second_vision/workers/serial_worker.py) the loop
structure exists, but almost nothing underneath it does real work:

| Piece | Actual state |
|---|---|
| `_open_serial_port(config)` | Returns `None`. **There is no port path to open** — `SystemConfig` has no `serial_port` field, and `--serial-port` appears only in a `main.py` docstring, never registered as a CLI argument |
| `_send_packet()` | No-op; its debug print is commented out, so nothing is observable |
| `_check_ack()` | Returns `True` unconditionally, so the consecutive-failure counter can never trip |
| `_send_heartbeat()` | Bare `pass`. **`_pack_heartbeat()` has zero callers** — no heartbeat is ever sent, so the ESP32 watchdog would fire on every quiet period |
| `_pack_motor_update()`, `_pack_hazard_alert()` | Implemented and reached |

Treat this workstream as **early**, not nearly-done.

### Next

1. Register a `--serial-port` CLI argument and plumb the path through to the worker.
2. Extract the packing functions into `core/protocol.py` so they are unit-testable without
   hardware, and write those tests.
3. Real `pyserial` open / write / read with the documented wire settings.
4. Wire the orphaned `_pack_heartbeat()` into the idle branch.
5. Real ACK handling and a decided failure policy (the current handler is a `TODO` print).
6. Joint UART bring-up against the finished firmware.

### Key files

`workers/serial_worker.py`, `core/protocol.py` (planned), `main.py` (worker startup).

---

## 5. Control panel + mode switching

**Role label:** control owner
**Purpose:** Physical switches and knobs that change system behaviour live, including
switching which models run.

### Status

Hardware is **in progress**. Both halves of the software are unimplemented:

- **Config reader** ([`workers/config_reader.py`](../src/second_vision/workers/config_reader.py)) —
  the text-protocol parsing (`S:key:value`, `M:mode`, `B:event`) and type casting are
  written, but `_open_config_port` / `_read_line` / `_close_config_port` are all stubs.
  **There is a live bug**: line 27 calls `config.udpate(...)` (typo for `update`), which
  would `AttributeError` the first time a real `S:` line arrives.
  `--config-port` is never registered as a CLI argument, so `main.py`'s
  `getattr(app.options_menu, "config_port", None)` is always `None` and the config reader
  thread never starts.
- **Mode switching** ([`pipeline/app.py`](../src/second_vision/pipeline/app.py)) —
  `trigger_rebuild()` exists and correctly defers through `GLib.idle_add`, which is the part
  that is easy to get wrong. But `get_pipeline_string()` and `_connect_callback()` do **not**
  branch on `config.pipeline_mode`, so a rebuild today just recreates the same fixed
  dual-branch pipeline.

### Next

1. Fix the `config.udpate` typo.
2. Register `--config-port`, plumb it, and implement real `pyserial` reads.
3. Make `get_pipeline_string()` / `_connect_callback()` mode-aware
   (detection-only / depth-only / both).
4. Verify the mode-switch announcement is heard before the rebuild blackout.

### Key files

`workers/config_reader.py`, `core/config.py`, `pipeline/app.py`.

---

## Field testing gate

**This happens last.** Once detection, depth, haptics and the control panel are converged,
the team runs the scenarios in [FIELD-TESTING.md](FIELD-TESTING.md) — schools, malls,
streets; best case, worst case, edge cases — and tunes the priority constants by ear.

Two standing caveats while testing:

- The device is **under test**. It is not to be relied on for real obstacle avoidance, and a
  visually-impaired tester has a dedicated spotter — the device does not detect stairs or
  curbs (DECISIONS D36), so the spotter owns ground-level hazards.
- Until depth lands, unclassifiable obstacles (poles, glass doors, curbs) are **silent** —
  that is expected, and noting which ones felt dangerous to miss is itself a deliverable for
  the depth workstream.

---

## Running the system

```bash
./scripts/run.sh --mock                     # no hardware needed
./scripts/run.sh --input usb                # real pipeline
./scripts/run.sh --input /dev/video0 --width 640 --height 480 --use-frame
```

`--headless`, `--debug-display`, `--serial-port` and `--config-port` appear in older docs
but are **not registered yet** — they will fail argparse. They are listed as tasks in the
workstreams above.

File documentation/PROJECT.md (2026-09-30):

# PROJECT.md — Second Vision Overview

## Project Title

**Second Vision: IoT-Based Smart Glass for the Visually Impaired**

## Researchers

- Kenzhu Aguilera
- Waldric Jude S. Garcia
- Kenth Razen M. Magbanua
- Reiven O. Jasa

---

## What It Does

Second Vision is a head-mounted assistive device that gives visually impaired users real-time spatial awareness through two complementary feedback channels:

1. **Audio (TTS)**: Announces *known* objects detected by AI — "person left", "car center", "bicycle right"
2. **Haptic (vibration motors)**: Provides proportional vibration for *all* obstacles (including those AI can't classify) — closer obstacle = stronger vibration

The device is used **without a white cane** (team decision, Sept 2026 — earlier drafts assumed one). It is the wearer's obstacle sense: anything standing in front of them, including low obstacles on the floor. **Stairs, drop-offs and step-ups are out of scope** — the software that tried to detect breaks in the ground exists in the code but is disabled because it is not reliable enough to be trusted (DECISIONS D36). The ground plane itself is still modelled every frame (it is how the floor is told apart from an obstacle). Users and demos must be told plainly that the device does not warn about stairs.

---

## Hardware

### Compute Unit
| Component | Spec |
|---|---|
| SBC | Raspberry Pi 5 (8GB RAM) |
| AI Accelerator | Hailo AI Hat+ (Hailo-8, 26 TOPS) |
| Camera | OV2640 USB Camera Module |
| OS | Raspberry Pi OS Trixie (64-bit) |

### Head Unit
| Component | Spec |
|---|---|
| Camera mount | Forehead (center, angled ~10-15° down) |
| Motor L | Vibration ERM — left temple |
| Motor C | Vibration ERM — forehead |
| Motor R | Vibration ERM — right temple |
| Audio | Bone-conduction earphones |

### Motor Controller
| Component | Spec |
|---|---|
| MCU | ESP32 (wired USB serial to RPi5) |
| Motor drivers | 3× N-channel MOSFETs (one per motor) |
| Flyback protection | 1N4148 diode across each motor |
| Power | 18650 Li-ion cell (3.7V, parallel motor wiring) |

### Control Panel
| Component | Spec |
|---|---|
| MCU | Arduino (wired USB serial to RPi5) |
| Inputs | Toggle switches (mode, TTS on/off), potentiometers (motor strength, cooldown), momentary button (status) |

---

## Software Stack

| Layer | Technology |
|---|---|
| Inference Runtime | HailoRT + GStreamer pipeline |
| Detection Model | YOLOv8n (compiled to HEF for Hailo-8) |
| Depth Model | SC-DepthV3 (compiled to HEF for Hailo-8) |
| Framework | `hailo_apps` (pip-installed library) |
| Application | `second_vision` Python package |
| TTS Engine | pyttsx3 / espeak-ng |
| Serial Protocol | Binary (RPi5 → ESP32), Text (Arduino → RPi5) |
| Language | Python 3.13 |

---

## System Data Flow

```
Camera → GStreamer Pipeline → Hailo-8 NPU
                                 │
                    ┌────────────┴────────────┐
                    ▼                         ▼
              YOLOv8n                   SC-DepthV3
           (detection)               (depth estimation)
                    │                         │
                    ▼                         ▼
            Detection Callback         Depth Callback
            (label + zone)          (zone proximity 0-255)
                    │                         │
              ┌─────▼─────┐            ┌──────▼──────┐
              │ TTS Worker │            │Serial Worker│
              │ (espeak-ng)│            │(binary pkts)│
              └─────┬──────┘            └──────┬──────┘
                    │                          │
                    ▼                     USB Serial
                Speaker                       │
               (audio)                   ┌────▼────┐
                                         │  ESP32   │
                                         │ 3× PWM  │
                                         └──┬─┬─┬──┘
                                            │ │ │
                                         L  C  R  Motors
```

---

## Key Design Principles

1. **Callbacks are fast** — GStreamer callbacks extract data and `put_nowait()` into queues. No blocking.
2. **Workers are independent** — Each daemon thread consumes from one queue, processes at its own pace.
3. **Config is shared** — Thread-safe `SystemConfig` object, updated by Arduino control panel, read by all workers.
4. **Stubs first** — Every component starts as a working stub. Replace internals incrementally.
5. **Two feedback modalities** — Detection → Audio (TTS), Depth → Haptic (motors). No cross-referencing.

---

## Development Modes

| Mode | Command | What it does |
|---|---|---|
| Mock | `--mock` | No hardware needed. Fake detections + depth data. For development on any machine. |
| Display | `--input usb` | Real pipeline with display windows. For visual verification. |
| Headless | `--input usb --headless` | Real pipeline, no display. For production / battery testing. |
| Full | `--input usb --serial-port /dev/ttyUSB0 --config-port /dev/ttyACM0 --headless` | Complete system. |

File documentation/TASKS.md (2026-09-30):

# TASKS.md — Status Board

> **Last synced: 2026-07-27.** This file is the **source of truth for status**.
> Tick boxes here as work lands. `.agents/*.md` handoffs remain the narrative record —
> the why, the decisions, the instructive failures — but they are local to one machine and
> are not the status board.
>
> Organised by the five workstreams in [PLAN.md](PLAN.md), which run concurrently.

## Status legend

- `[ ]` Not started
- `[/]` In progress
- `[x]` Complete
- `[~]` Blocked / waiting on a dependency

---

## Foundation (done)

- [x] Package layout under `src/second_vision/`
- [x] `core/config.py` — thread-safe `SystemConfig`
- [x] `mock/data_generator.py` — fake detections + depth for `--mock`
- [x] `main.py` — orchestrator, worker startup, mock/pipeline split
- [x] `pipeline/app.py` — `SecondVisionApp`, dual-branch pipeline, `_connect_callback`
- [x] `scripts/run.sh` — venv + Hailo env + `PYTHONPATH`, passes args through
- [x] `--mock` runs end-to-end with no hardware

> Note: `SecondVisionApp` extends `GStreamerApp`, **not** `GStreamerParallelApp` — that
> class exists only in the prototyping repo and is not importable from the installed
> library. The dual-branch pipeline is built inline here.

---

## 1. Object detection callbacks — *detection owner*

- [x] Extract detections, compute zone from bbox centre
- [x] Zone hysteresis `0.22 / 0.25 / 0.75 / 0.78`, holding previous zone in the bands
- [x] Per-track history keyed by tracker ID
- [x] Stale-track cleanup (`STALE_TRACK_FRAMES = 15`), including on empty frames
- [x] Head-turn suppression, gated by `HEAD_TURN_MIN_TRACKED = 3`
- [x] "leaving to X" / "still X" event phrasing
- [x] False-positive confirmation gate (`MIN_CONFIRMATION_SECONDS = 0.3`, `first_seen`)
- [x] "multiple X" wording, tallied from `track_history` after stale cleanup
- [x] "multiple X" composes with all phrase types, not just first sightings
- [x] cv2 debug overlay: zone tints, dividers, boxes, track IDs, FPS
- [x] Per-detection priority/tier, one winner per frame → TTS mailbox
- [ ] **Validate on real hardware**: confirmation gate, "multiple X", flicker-tolerant tally
      (all three verified only against mocked-hailo harnesses)
- [ ] Decide whether to tune `CONFIDENCE_THRESHOLD` / NMS thresholds at the source
- [ ] Settle the final detection class list
- [ ] Pluralization (`person` → `people`) — deferred until the class list is settled
- [ ] Remove or repurpose `zone_since` (computed and stored every frame, read by nothing)

---

## 2. Depth estimation callbacks — *depth owner*

> The approach is **under active design in the prototyping repo** and changing rapidly.
> Tasks here cover the port into this repo, not the algorithm design — see
> [PLAN.md](PLAN.md#2-depth-estimation-callbacks).

- [x] Placeholder `_process_real_depth` keeping the `serial_queue` interface alive
- [x] Depth-branch FPS scaffolding on `user_app_callback_class`
- [/] Design and validate the post-processing in the prototyping repo
- [ ] Port into this repo — verify imports resolve here
- [ ] Ensure it coexists cleanly with the haptic/serial path
- [ ] Apply this repo's coding standards before it lands
- [ ] Replace the placeholder `_process_real_depth`
- [x] ~~Wire real hazard output~~ — **disabled by decision (D36)**: `hazard=False` is now deliberate, gated by `GROUND_HAZARD_ENABLED`
- [ ] Port/author unit tests for the depth math in this repo
- [ ] Tune parameters against real captures
- [ ] Decide where depth post-processing state lives across a pipeline rebuild
- [ ] **After the port lands and is accepted: update the documentation immediately**
      (PLAN.md, ARCHITECTURE.md depth section, DECISIONS.md, this file)

---

## 3. TTS — *TTS owner*

- [x] `PriorityMailbox` — `offer` / `take` / `peek`, keep-higher, ties to newer
- [x] Composite priority score (confidence, area, zone, class, recency penalty)
- [x] Urgency tier model (`normal` / `urgent`)
- [x] `preempts()` — tier-OR-margin, with `PREEMPT_USE_TIER` flag for on-device A/B
- [x] Serialized interruptible speech (~50 ms preempt poll while speaking)
- [x] Minimum inter-utterance gap, skipped by an urgent pending item
- [x] Hard repeat floor (`MIN_REPEAT_INTERVAL = 10.0`) with urgent bypass
- [x] Removed the old `CooldownManager`; suppression now lives in one layer
- [x] espeak-ng primary, pyttsx3 fallback for dev machines
- [x] All tunables consolidated as named constants in `core/priority.py`
- [x] `tests/test_priority.py` — **19 tests passing**
- [ ] Wire the `W_APPROACH` approach-velocity hook (reserved, currently `0.0`)
- [ ] Confirm on-device that the layering fix holds under real load
- [~] Tune weights / margins / gap by ear — **scheduled last**, see the field-testing gate

---

## 4. ESP32 vibration motors — *firmware owner*

### ESP32 side — complete

- [x] Parse the binary protocol (start byte, type, payload, checksum)
- [x] Validate the XOR checksum
- [x] `MOTOR_UPDATE` → 3× PWM
- [x] `HAZARD_ALERT` → pulsing pattern override
- [x] `HEARTBEAT` → watchdog reset
- [x] Send ACK on a valid packet
- [x] 3-second watchdog → all motors to 0

### RPi side — **UART comms still being built**

- [x] `_pack_motor_update()` and `_pack_hazard_alert()` implemented and reached
- [ ] Register a `--serial-port` CLI argument (**does not exist** — currently only in a
      `main.py` docstring)
- [ ] Plumb the port path through to the worker (`SystemConfig` has no `serial_port` field,
      so `_open_serial_port(config)` has nothing to open)
- [ ] Extract packing into `core/protocol.py` (testable without hardware)
- [ ] `tests/test_protocol.py` — pack/unpack/checksum for every message type
- [ ] Real `pyserial` open / write / read
- [ ] Wire the orphaned `_pack_heartbeat()` — **it currently has zero callers**, so no
      heartbeat is ever sent and the ESP32 watchdog would fire on every quiet period
- [ ] Real ACK reading (`_check_ack` returns `True` unconditionally today)
- [ ] Decide and implement the ACK-failure policy (the handler is a `TODO` print)
- [ ] Restore observable send logging (`_send_packet`'s print is commented out)
- [ ] Joint UART bring-up: Pi ↔ ESP32 end to end, motors responding to real depth

---

## 5. Control panel + mode switching — *control owner*

### Config reader

- [x] Text protocol parsing (`S:key:value`, `M:mode`, `B:event`) and type casting
- [ ] **Fix the `config.udpate(...)` typo** (should be `update`) — would `AttributeError`
      on the first real `S:` line
- [ ] Register a `--config-port` CLI argument — **does not exist**, so
      `getattr(app.options_menu, "config_port", None)` is always `None` and the config
      reader thread never starts
- [ ] Real `pyserial` reads (`_open_config_port` / `_read_line` / `_close_config_port`)
- [~] Verify a potentiometer changes `motor_strength` live — blocked on panel hardware
- [~] Verify a toggle changes `tts_enabled` live — blocked on panel hardware

### Mode switching

- [x] `trigger_rebuild()` defers correctly through `GLib.idle_add`
- [ ] Make `get_pipeline_string()` branch on `config.pipeline_mode`
- [ ] Make `_connect_callback()` branch on `config.pipeline_mode`
- [ ] Detection-only / depth-only / both pipeline builders
- [ ] Verify the mode announcement is heard before the rebuild blackout
- [ ] Decide where depth post-processing state is reset across a rebuild (with depth owner)

---

## Cross-cutting / not owned by one stream

- [ ] `--headless` flag → `fakesink` (documented in older plans, never implemented)
- [ ] `--debug-display` composite OpenCV window (the current overlay is in-callback cv2)
- [ ] `tests/test_config.py` — `SystemConfig` thread safety
- [ ] `tests/test_depth_utils.py` — lands with the depth port
- [ ] Decide whether to delete `main2.py` (temporary smoke-test script)
- [ ] Decide whether to trim the `TBR-*` draft files
- [ ] **Open interface question** *(parked — ground-hazard detection is disabled, D36)*:
      hazard *direction*. The prototype's ground-hazard detection distinguishes `"down"`
      (drop-off) from `"up"` (curb), but the `serial_queue` contract has no field for it and
      `HAZARD_ALERT`'s payload is severity + pattern. Only needs settling if the feature is
      ever re-enabled.

---

## Field testing — **last**

- [~] Run the scenarios in [FIELD-TESTING.md](FIELD-TESTING.md) and tune by ear.
      Blocked by design: this is the final activity, after the four build streams converge.

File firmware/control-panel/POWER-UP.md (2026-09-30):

# Power-up checklist — X1202 → protoboard → ESP32

Follow in order. Every check happens **before** the ESP32 is in the circuit, so
a mistake costs a re-wire instead of a board.

You need a multimeter. There is no reliable way to verify polarity without one,
and reversed 5 V on the ESP32's `5V` pin destroys it instantly — most NodeMCU
boards have no reverse-polarity protection.

---

## 0. Before you start

- **ESP32 NOT connected to the protoboard.** Leave it out entirely.
- **USB unplugged from the ESP32.** USB 5 V and the `5V` pin are the same net on
  this DevKit, with no isolation diode. Never have both connected.
- Have the panel firmware already flashed (`bench` or `panel`) — do that over
  USB from the laptop first, then unplug.

---

## 1. Identify the XH2.54 polarity  — the step that saves the board

With the X1202 running and its output connector free:

1. Meter to **DC volts**, 20 V range.
2. Black probe on a known ground — the Pi's **pin 6**, or any header GND. The
   X1202 sits on the Pi's header, so its ground and the Pi's are one node.
3. Red probe on each XH2.54 pin in turn.

| Reading | Meaning |
|---|---|
| **+4.9 to +5.2 V** | this is the **5 V** pin |
| **0 V** | this is **GND** |
| **negative** | probes reversed — swap and re-read, do not "correct" it in wiring |
| **above 5.5 V** | STOP. Wrong connector, or the UPS is misconfigured |

**Write down which physical pin is which.** Do not rely on wire colour: XH2.54
leads are frequently red/black in either order, and the silkscreen can be
ambiguous under a stacked HAT.

---

## 2. Build the protoboard with no ESP32 in it

Two positive rails, kept apart:

| Rail | Source | Feeds |
|---|---|---|
| **5V** | X1202 XH2.54 | the ESP32's `5V` pin — nothing else |
| **3V3** | the ESP32's own `3V3` **output** | the potentiometer only |
| **GND** | X1202 GND | everything's return |

The 3V3 rail is fed *by* the ESP32, not by the X1202. It carries nothing until
the board is in and powered.

---

## 3. Continuity check — power OFF

Disconnect the X1202 feed. Meter to **continuity / beep**:

| Between | Must be |
|---|---|
| 5V rail ↔ GND rail | **silent.** A beep is a short — find it before powering |
| 5V rail ↔ 3V3 rail | **silent.** These must never join |
| 3V3 rail ↔ GND rail | silent (the pot's 10 kΩ may read as resistance, not a beep) |
| each rocker's two legs | beep in one switch position only |

A beep on the first two rows is exactly the fault that would put 5 V somewhere
it must not go. Fix it here.

---

## 4. Rails live, ESP32 still out

Reconnect the X1202 feed. **ESP32 still not inserted.**

| Measure | Expect |
|---|---|
| 5V rail → GND rail | +4.9 to +5.2 V |
| polarity | red probe on 5V rail reads **positive** |
| 3V3 rail → GND rail | **0 V** — nothing drives it yet |

If the 3V3 rail shows anything, it is joined to the 5V rail. Go back to step 3.

---

## 5. Insert the ESP32

Power off first. Insert, checking orientation against
`docs/breadboard_wiring.svg` — pin 1 (`3V3`) and the `5V` pin are at opposite
ends of the left column, so a board in backwards puts 5 V on the 3V3 pin.

Power on and, within about two seconds:

| Check | Expect |
|---|---|
| red power LED | **lit** |
| 3V3 rail → GND | now **+3.2 to +3.4 V** — the regulator is working |
| board temperature | cool. **Anything warm: power off immediately** |

A warm regulator means a short. That is the same symptom that turned up earlier
in this project when a switch leg bridged the 3V3/GND row.

---

## 6. Verify the link from the Pi

```bash
cd ~/Projects/Second-Vision/worktrees/feature-camera-feed
source my_hailo_env/bin/activate
cd firmware/control-panel
./check_link.sh
```

All three stages should pass **with no USB attached anywhere**. That is the
proof that the X1202 is genuinely powering the panel.

---

## If you have no multimeter

Do not guess the polarity. Options, best first:

1. **Borrow one.** Even the cheapest continuity/DC-volts meter is enough for
   every check above.
2. **Keep using USB power** for now. The panel works fully on USB — the link,
   the rockers and the protocol are all verified that way. Only the final
   untethered configuration needs the X1202 feed, and it can wait.

Option 2 is a legitimate hold: nothing in the software depends on where the 5 V
comes from.

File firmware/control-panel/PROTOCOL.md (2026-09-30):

# Control panel wire protocol — v1

Frozen contract between `src/control_panel.cpp` (ESP32) and
`src/second_vision/workers/config_reader.py` (Raspberry Pi).

This file lives in `firmware/control-panel/` on purpose: it is the only document
that travels with the firmware when the folder is copied to another machine, so
the folder is self-describing wherever it lands.

---

## Transport

| Property | Value |
|---|---|
| Medium | UART, 3.3 V logic, no level shifter |
| Baud | **9600**, 8N1 |
| Direction | **One-way, ESP32 → Pi.** The panel never reads |
| Flow control | None |
| Terminator | `\n` (0x0A) only — no `\r` |
| Encoding | ASCII; lowercase keys and values |
| Max line | **64 bytes** (longest defined line is 22) |

### Two transports, one binary

Every line is emitted **identically and in the same order** on both:

| Path | Pins | Purpose |
|---|---|---|
| `Serial2` | ESP32 GPIO23 → Pi **pin 21** (GPIO9, `uart3-pi5`) | deployment |
| `Serial` | USB CDC | bench debugging, and testing on a laptop with no Pi |

No build flag, no mode switch. The Pi link is deliberately **not** UART0: UART0
is the USB serial, and the ROM bootloader dumps its 115200 log there on every
reset. On its own UART the Pi never sees that garbage — but a USB listener
still will, so receiver rule 1 stays mandatory.

---

## Line types

### `V:panel:<n>` — boot only

    V:panel:1

First line after reset. `1` is this protocol version.

### `S:<key>:<value>` — settings

| Line | Values |
|---|---|
| `S:tts_enabled:<v>` | `0` \| `1` |
| `S:vibration_enabled:<v>` | `0` \| `1` |
| `S:motor_strength:<v>` | `0.00`–`1.00`, **always 2 decimals** |

### `M:<mode>` — pipeline mode

`M:detection` \| `M:depth` \| `M:both` \| `M:none`

Derived from the two rocker positions, never from a counter:

| DETECT | DEPTH | mode |
|---|---|---|
| on | on | `both` |
| on | off | `detection` |
| off | on | `depth` |
| off | off | `none` |

`M:none` means **run nothing** — not "run both and mute". A model with no route
to the user is wasted Hailo time and battery.

### `B:<name>` — events

| Line | Meaning |
|---|---|
| `B:status` | STATUS pressed — the Pi speaks the full config aloud |
| `B:alive` | heartbeat, every 10 s |

---

## Emission triggers and ordering

**`M:` is always the LAST line of a state burst.** Treat it as a commit marker:
when it arrives, everything before it in that burst is current. Never act on a
partial burst.

**Boot** — rocker positions are read from hardware, never assumed:

    V:panel:1
    S:tts_enabled:<v>
    S:vibration_enabled:<v>
    S:motor_strength:<v>
    M:<mode>

**Either rocker moves** — both flags are sent, so the burst is self-contained:

    S:tts_enabled:<v>
    S:vibration_enabled:<v>
    M:<mode>

**Pot moves** (deadbanded, >80 counts of 4095) — standalone, no `M:`:

    S:motor_strength:<v>

**STATUS pressed** (debounced 50 ms):

    B:status

**Every 10 s** — liveness, then a full state burst:

    B:alive
    S:tts_enabled:<v>
    S:vibration_enabled:<v>
    S:motor_strength:<v>
    M:<mode>

### Why the heartbeat carries state

Panel and Pi share the X1202 UPS, so they power up **together** and the Pi is
~30 s from opening the port. A one-shot boot report is lost every time, leaving
`SystemConfig` disagreeing with switches the user can see and feel — the exact
failure reading latching switches at boot is meant to prevent. No delay the
panel could reasonably sit through would close that gap.

The re-announce also covers a dropped byte and any restart of `main.py` while
the panel stays powered, which is the common case in development.

---

## Receiver rules — REQUIRED

1. **Discard unparseable lines silently.** The ROM bootloader's 115200 log
   arrives as garbage at 9600 on the USB path. Normal; must never raise.
2. **Ignore unknown `S:` keys.** A future panel may send keys v1 does not define.
3. **Ignore unknown `M:` values**, holding the last known-good mode.
4. **Never crash on a malformed line.** Reader-thread survival beats any single
   message.
5. **Treat missing `B:alive` as a fault.** Silence >30 s means the panel is not
   responding; say so rather than acting on stale settings indefinitely.
6. **Act only on CHANGES.** This one is load-bearing, not hygiene: the panel
   re-announces its whole state every 10 s, and a receiver that acted
   unconditionally would tear down and rebuild the Hailo pipeline every 10
   seconds, with a TTS announcement each time.

### Semantics

- **`tts_enabled` and `vibration_enabled` change autonomously.** They are
  consequences of rocker position, not button presses, and move at boot and on
  every flip. Any logic assuming they only change on explicit user action is
  wrong.
- **The panel is authoritative** for these four values. It reports physical
  reality; the Pi must not hold a contradicting internal state.

---

## Build options

| Env | Use | Difference |
|---|---|---|
| `panel` | deployment | everything present |
| `bench` | laptop, bare board, no breadboard | `-D HAVE_POT=0` |
| `polarity` | bring-up | separate sketch: raw pin states |

**`HAVE_POT=0` omits `S:motor_strength` entirely** — from the boot burst, the
heartbeat burst, and the pot handler. Receivers must therefore not *require*
that key; the Pi simply keeps its existing `motor_strength`. Ordering is
unchanged and `M:` is still the commit marker, so this is a build option, not a
protocol variant, and the version stays 1.

Why it exists: GPIO34 is input-only with no internal pull-up, so an unfitted pot
floats and the 80-count deadband — sized for a wired pot's dither — is exceeded
constantly. Measured on a bare board: **~1,625 spurious `S:motor_strength` lines
in 30 s** (~54/s), enough to saturate a 9600 link on both transports.

## Testing without a Raspberry Pi

    pip install pyserial
    python3 panel_monitor.py /dev/ttyUSB0     # or COM7 on Windows

`panel_monitor.py` ships beside this file and depends on nothing but pyserial —
no Hailo, no GStreamer, no repo checkout. It validates rather than tolerates:
`M:` ordering, unknown keys, value ranges and decimal format, version mismatch,
the `B:alive` window, and whether the mode agrees with the flags in its own
burst. Add `--raw` to see every byte as received.

---

## Versioning

`V:panel:<n>` at boot. Bump for:

- a new or removed message type
- a changed value range or format
- a changed ordering guarantee

Adding a new `S:` key does **not** require a bump — receivers already ignore
unknown keys (rule 2). Neither does adding an emission trigger, provided the
line format and ordering are unchanged; that is why the 10 s re-announce is
still v1.

---

## Out of scope

- **Pi → ESP32 messages.** One-way by design; a reverse channel is a version bump.
- **The `B:status` spoken payload** — Pi-side policy, not protocol.
- **The motor-controller link** (binary, 115200, separate UART) — unrelated.

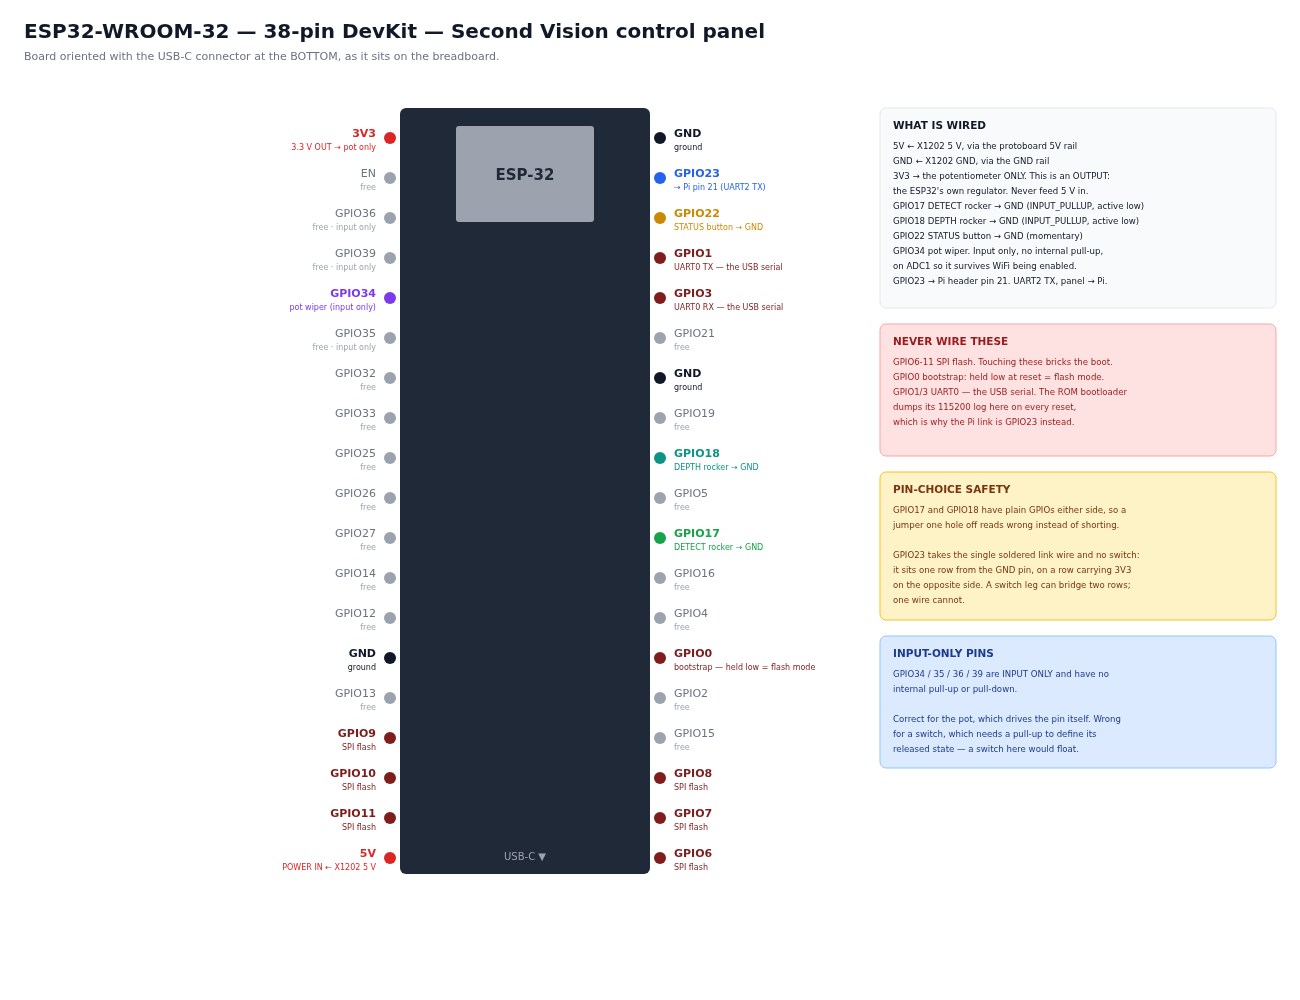
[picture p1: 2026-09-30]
firmware/control-panel/docs/esp32_pinout.png

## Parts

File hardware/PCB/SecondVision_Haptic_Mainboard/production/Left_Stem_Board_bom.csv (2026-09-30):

Designator | Footprint | Quantity | Value | LCSC Part #
BTN_VOL_DOWN1, BTN_VOL_UP1 | SW_SPST_B3U-1000P | 2 | SW_Push
D1 | D_SOD-123 | 1 | 1N5401
PAD_5V_L1, PAD_D0_LEFT1, PAD_GND_L1, PAD_VOL_DOWN1, PAD_VOL_UP1 | PinHeader_1x01_P2.54mm_Vertical | 5 | Conn_01x01
Q1 | SOT-23 | 1 | 2N7000
R1 | 0603 | 1 | R
VIB_LEFT1 | PinHeader_1x02_P2.54mm_Vertical | 1 | Conn_01x02

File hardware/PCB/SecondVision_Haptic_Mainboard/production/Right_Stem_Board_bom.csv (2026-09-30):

Designator | Footprint | Quantity | Value | LCSC Part #
D2, D3 | D_SOD-123 | 2 | 1N5401
PAD_5V_R1, PAD_D1_CENTER1, PAD_D2_RIGHT1, PAD_GND_R1 | PinHeader_1x01_P2.54mm_Vertical | 4 | Conn_01x01
Q2, Q3 | SOT-23 | 2 | 2N7000
R2, R3 | 0603 | 2 | R
VIB_CENTER1, VIB_RIGHT1 | PinHeader_1x02_P2.54mm_Vertical | 2 | Conn_01x02

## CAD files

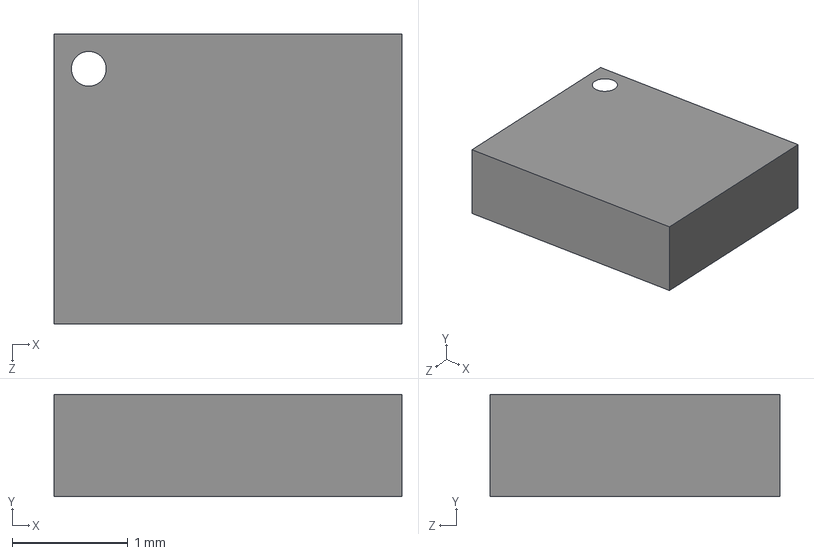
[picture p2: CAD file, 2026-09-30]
hardware/PCB/snapmagic_libs/BMI160/BMI160.step
3.00 x 0.88 x 2.50 mm

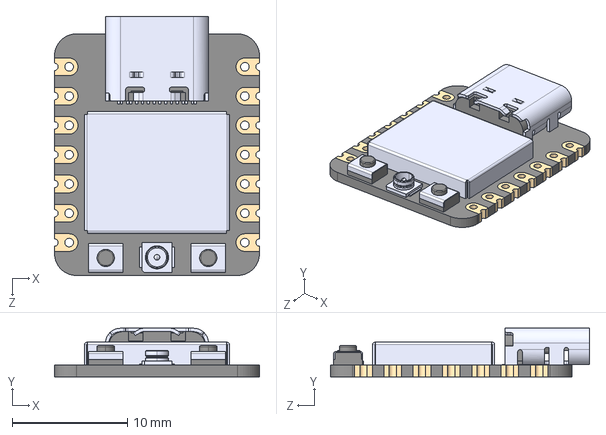
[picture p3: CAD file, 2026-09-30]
hardware/PCB/snapmagic_libs/XIAO_ESP32C3/XIAO_ESP32C3.step
17.8 x 4.21 x 22.5 mm

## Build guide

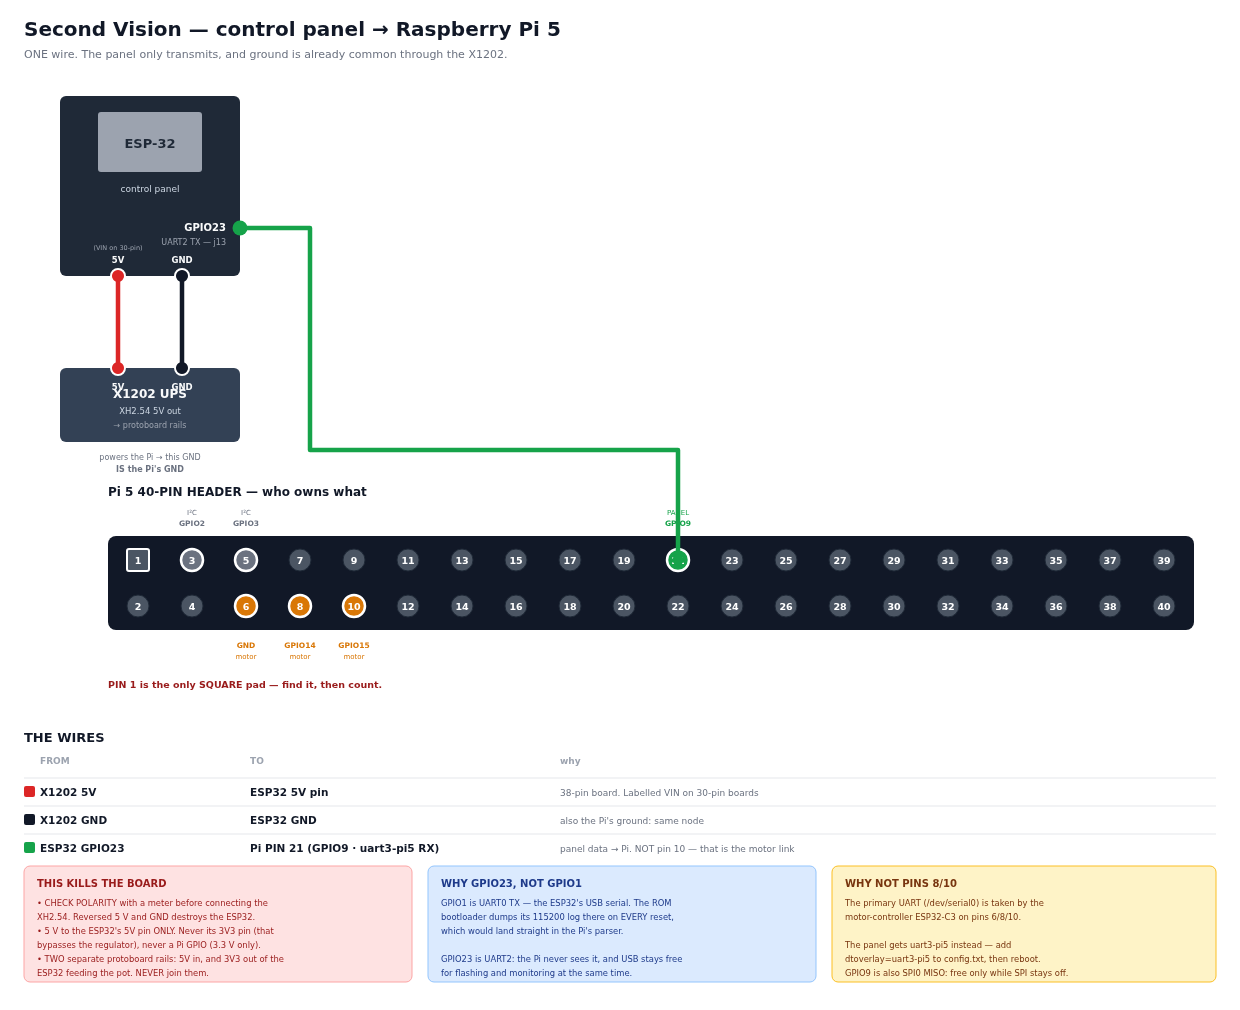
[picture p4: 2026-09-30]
firmware/control-panel/docs/pi_link_wiring.png

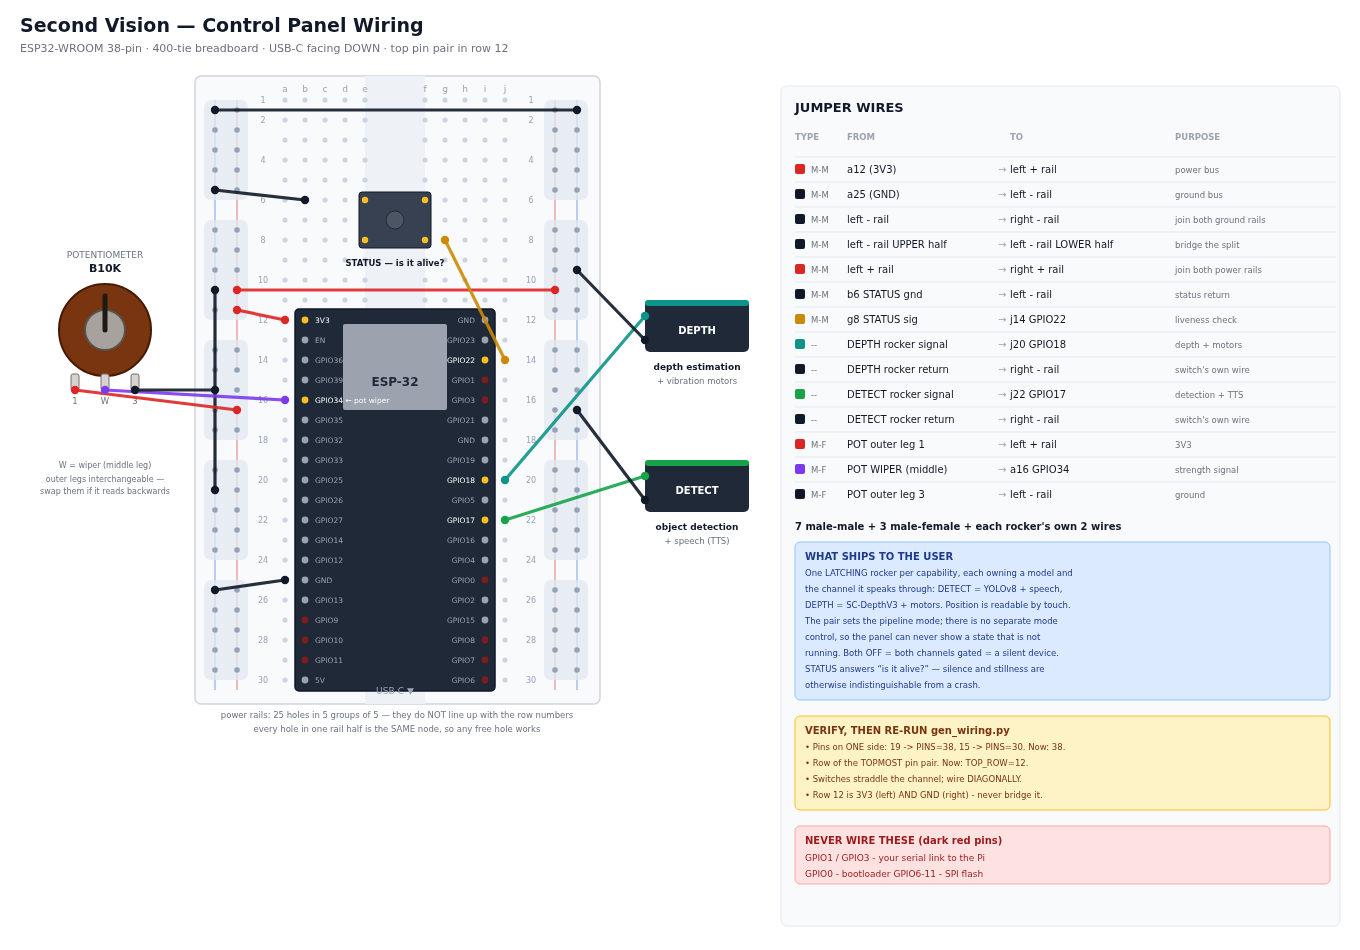
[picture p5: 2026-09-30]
firmware/control-panel/docs/breadboard_wiring.png

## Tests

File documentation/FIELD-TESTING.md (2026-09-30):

# FIELD-TESTING.md — Real-World Scenarios for Tuning the TTS Priority System

Purpose: extensively test and tune the announcement prioritization / preemption /
pacing behavior (the queue revamp — see `.agents/handoff_v3.md`) outside a single
room, in schools, malls, and streets. Best case, worst case, edge cases, and
deliberately-unaccounted cases.

Every tunable lives in one file: `src/second_vision/core/priority.py` (plus
`CONFIDENCE_THRESHOLD`, `MIN_CONFIRMATION_SECONDS`, `MIN_REPEAT_INTERVAL`,
`STALE_TRACK_FRAMES`, `HEAD_TURN_*` in `src/second_vision/pipeline/callbacks.py`).
Change a value, re-run, re-test the relevant scenario.

---

## 0. Before you go — safety, caveats, setup

**Safety (read first):**
- The device is **under test** — do **not** rely on it for real obstacle avoidance.
- Prefer **sighted testers** wearing the rig. If a visually-impaired teammate tests,
  they have a **dedicated spotter** the whole time. The device does **not** detect
  stairs, curbs or ledges (DECISIONS D36) — the spotter owns those.
- **Streets/traffic**: stay on the sidewalk. Start with **parked or slow-moving**
  vehicles. Never step into a roadway to "trigger" a car detection. One person's only
  job is watching for real hazards, not the device.
- Malls/schools: get permission where needed; don't film bystanders' faces
  identifiably if your school/mall rules forbid it.

**Current scope caveats:**
- **TTS only.** Depth → haptic motors is still a stub, so unclassifiable obstacles
  (poles, glass doors, curbs, walls, hanging signs) are **silent** right now. That's
  expected — note them, but they're the depth channel's job later.
- Announcements are limited to the detector's classes (YOLO/COCO). Anything off-list
  is invisible to the TTS channel.

**Recording ground truth (so you can correlate what it SAW vs SAID):**
- Run with a **timestamped stdout log** on the Pi, e.g.:
  ```bash
  ./scripts/run.sh --input usb 2>&1 | while IFS= read -r l; do echo "$(date +%H:%M:%S.%3N) $l"; done | tee ~/svtest_$(date +%F_%H%M).log
  ```
  Every announcement prints as `[TTS] '...'`; the log is your transcript.
- Simultaneously record the **scene** (a phone/GoPro pointed roughly where the camera
  looks) with **audio**, so you can line up "what was in front" with "what it said."
- If a display is attached, the cv2 overlay shows the zone lines, per-object IDs, and
  FPS — useful for confirming zone/boundary behavior.
- After each run, note **subjective feel**: too talkative? too quiet? did it interrupt
  well? did it miss something important?

---

## 1. How to read results — symptom → parameter tuning map

Use this table after every session. Symptoms are what you HEAR/observe; the fix is the
direction to nudge the constant.

| Symptom observed | Likely parameter | Adjust |
|---|---|---|
| Machine-gun / rapid-fire chatter | `MIN_UTTERANCE_GAP` | ↑ (e.g. 0.5 → 0.8) |
| Feels laggy / misses fast events | `MIN_UTTERANCE_GAP` | ↓ |
| Same object nags too often ("still" spam) | `MIN_REPEAT_INTERVAL` | ↑ (10 → 15) |
| Forgets a persistent object is still there | `MIN_REPEAT_INTERVAL` | ↓ |
| In a crowd, same object dominates; others never spoken | `RECENCY_PENALTY_MAX` ↑ / `RECENCY_DECAY_SECONDS` ↑ | stronger/longer suppression of just-spoken items |
| A just-spoken object never comes back even when alone | `RECENCY_DECAY_SECONDS` | ↓ |
| Interrupts too eagerly on trivial changes (twitchy barge-in) | `PREEMPT_MARGIN` | ↑ (0.75 → 1.2) |
| Something clearly more important won't cut in | `PREEMPT_MARGIN` ↓ / add to `URGENT_CLASSES` | |
| Too many "urgent" barge-ins, feels alarmist | `URGENT_ABS_THRESHOLD` | ↑ (3.2 → 3.6) |
| A very close centered object DOESN'T cut through | `URGENT_ABS_THRESHOLD` ↓ / check `URGENT_CLASSES` | |
| Wrong things ranked as important | `CLASS_WEIGHTS`, `ZONE_WEIGHTS`, `W_*` | rebalance |
| Announces phantoms / flickery false positives | `CONFIDENCE_THRESHOLD` ↑ / `MIN_CONFIRMATION_SECONDS` ↑ | |
| Misses real objects (small/far/poor light) | `CONFIDENCE_THRESHOLD` ↓ | |
| Slow to announce a real fast-appearing object | `MIN_CONFIRMATION_SECONDS` | ↓ |
| Spams "leaving to X" when you turn your head | `HEAD_TURN_RATIO` ↓ / `HEAD_TURN_SUPPRESS_SECONDS` ↑ | |
| Zone flips back and forth for a boundary-standing object | zone hysteresis band (`*_BOUNDARY`) | widen the gap |
| Two same objects not called "multiple" | confirmation timing / `STALE_TRACK_FRAMES` | verify both confirmed |

**Golden rule of tuning:** change **one** parameter at a time, re-run the **same**
scenario, and log before/after. The two goals are always in tension — *inform enough*
vs *don't overwhelm* — so you're finding a balance, not a "correct" number.

---

## 2. Best-case / baseline (does it behave in the open?)

**B1 — Single approacher, open space** *(schoolyard, empty plaza)*
- Setup: wide open area, one person walks slowly toward the tester from ~10 m, straight
  down the center.
- Do: stand still, let them approach, pass, and leave.
- Expect: one clean first announcement once confirmed (~0.3 s in), periodic "person
  still center" at the repeat cadence, no chatter, no layering.
- Pass: exactly one voice at a time; "still" reminder roughly every `MIN_REPEAT_INTERVAL`.
- Tunes: `MIN_CONFIRMATION_SECONDS`, `MIN_REPEAT_INTERVAL`, `MIN_UTTERANCE_GAP`.

**B2 — Cross-and-leave** *(hallway, sidewalk)*
- Setup: person starts in your center, walks out to your left or right and away.
- Expect: "person leaving to left/right" once on the transition, then silence.
- Pass: the leaving phrase fires **once**, cleanly, not repeatedly.
- Tunes: zone boundaries/hysteresis, leaving-center logic.

**B3 — Calm stroll** *(quiet mall wing, park path)*
- Setup: tester walks a fixed 30–60 s route with a few scattered people/objects.
- Expect: occasional, calm announcements — informative but restful.
- Pass: you'd describe the cadence as "calm," not "nagging" or "silent."
- Tunes: `MIN_UTTERANCE_GAP`, recency, `MIN_REPEAT_INTERVAL`.

---

## 3. Worst-case / overwhelm & urgency (the hard stuff)

**W1 — Dense crowd (the overwhelm test)** *(mall concourse, school corridor between classes)*
- Setup: stand at the edge of a busy flow of people; many bodies, constant motion.
- Do: hold position 60–90 s, then walk through slowly.
- Watch for TWO failure modes:
  1. **Overwhelm** — non-stop talking, can't think. → raise `MIN_UTTERANCE_GAP`,
     strengthen recency, raise `MIN_REPEAT_INTERVAL`.
  2. **Starvation** — because only the single highest-priority item is kept per moment,
     is anything *important* going unspoken for too long? → check recency decay so the
     spotlight rotates; consider class/zone weights.
- Pass: the tester feels *aware of the busiest/closest threats* without being buried.
  This is the central best-vs-worst tradeoff — expect to spend the most time here.
- Tunes: `MIN_UTTERANCE_GAP`, `RECENCY_*`, `MIN_REPEAT_INTERVAL`, `ZONE_WEIGHTS`.

**W2 — Vehicle at a crossing (preemption / urgency)** *(quiet street corner, SAFELY from the curb)*
- Setup: tester on the sidewalk facing a driveway/parking exit. A teammate drives a car
  slowly into the center of view, or use cars already pulling out. **Spotter mandatory.**
- Ideal trigger: while the device is mid-"person left" for a pedestrian, the car enters
  center.
- Expect: the car (urgent class + center) **barges in** — the current utterance is cut
  and "car center" plays immediately.
- Pass: urgent car interrupts within a fraction of a second; it does NOT wait its turn.
- Tunes: `URGENT_CLASSES`, `URGENT_ABS_THRESHOLD`, `PREEMPT_MARGIN`, and try the
  `PREEMPT_USE_TIER = False` (pure-margin) variant here to compare feel.

**W3 — Head-scanning a busy scene** *(mall atrium, street with shops)*
- Setup: stand in a populated area and pan your head left↔right as a user naturally would.
- Expect: the collective apparent motion is recognized as a head turn — you do **not**
  get a flood of "leaving to left/right" for every object.
- Pass: panning is quiet; genuine object transitions still announced when you're still.
- Tunes: `HEAD_TURN_RATIO`, `HEAD_TURN_DELTA`, `HEAD_TURN_MIN_TRACKED`,
  `HEAD_TURN_SUPPRESS_SECONDS`.

**W4 — Rapid oscillation (the original layering bug, in the wild)**
- Setup: have a teammate walk quickly back and forth across your center↔side boundary,
  or weave in front of you.
- Expect: **no overlapping speech ever** — one utterance at a time; sensible
  leaving/still phrasing, not a stutter of half-spoken words.
- Pass: zero layering (this is the bug the revamp fixed — confirm it stays fixed).
- Tunes: mostly a correctness check; if phrasing thrashes, look at hysteresis and
  `MIN_UTTERANCE_GAP`.

---

## 4. Edge cases

**E1 — Boundary loiterer.** Someone stands right on a zone line (~22–25% or 75–78% of
frame width). Expect a **stable** zone (hysteresis holds it), not flip-flopping. Tune the
boundary band if it jitters.

**E2 — "Multiple X."** Two+ people (or two of the same class) stand together in one zone.
Expect "multiple person center" once both are confirmed. If it says singular, they may
not both be clearing `MIN_CONFIRMATION_SECONDS`, or one keeps getting evicted
(`STALE_TRACK_FRAMES`).

**E3 — Blip / quick cross.** Someone darts across the far edge of view for <0.3 s.
Expect **no announcement** (the confirmation gate eats it). If it blurts a phantom, raise
`MIN_CONFIRMATION_SECONDS` or `CONFIDENCE_THRESHOLD`.

**E4 — Sudden close-up.** A person steps right in front of the tester, filling the center
of the frame. Expect this to cross `URGENT_ABS_THRESHOLD` (big area + center + confident)
and behave as **urgent** — barging in if something was talking. Verify the threshold
feels right: does "person right in my face" cut through? Should it?

**E5 — Priority duel.** Arrange a routine object (a person standing calmly to your left,
generating "still" reminders) and then introduce a higher-priority one (a car in center,
or someone stepping close-center). Expect the higher-priority one to win the moment and
preempt if needed. Tune `PREEMPT_MARGIN` / weights until the "who wins" calls feel right.

**E6 — Persistent companion.** A friend walks **alongside** the tester in center for a
full minute. Expect "person still center" every `MIN_REPEAT_INTERVAL`. Decide as a team:
is a steady companion worth repeating? This may motivate a future "quiet a stable,
non-approaching object" rule — log your judgment.

**E7 — Mode announcement over a busy scene** *(only if the Arduino config panel is wired)*.
Flip the mode switch during W1. Expect "…mode" to be heard **immediately** (announcements
are urgent) even amid crowd chatter.

---

## 5. Unaccounted / discovery cases (find what the design doesn't handle)

These aren't expected to "pass" — they're to surface gaps. Log everything.

**U1 — Fast approacher from the side (the reserved-hook gap).** A cyclist/jogger/scooter
approaches quickly from your left or right. Because approach-velocity is **not yet wired**
(`W_APPROACH = 0`) and side zones are down-weighted, it likely won't be urgent until it's
already large/close. **Measure how late** the urgent call comes — this is the concrete
evidence for whether to prioritize wiring the approach term next.

**U2 — Unclassifiable obstacles.** Walk past glass doors, poles, planters, low bollards,
hanging signs, a wall you approach head-on. Expect **silence** (no class → no TTS). Note
which of these felt *dangerous to miss* — that's the requirements list for the depth/haptic
channel.

**U3 — False positives from imagery.** Posters/ads/mannequins/screens showing people or
cars; mirrored columns and glass storefronts (reflections of real people). Expect some
phantom announcements. Log frequency → informs `CONFIDENCE_THRESHOLD` /
`MIN_CONFIRMATION_SECONDS`, and whether certain locations are just hostile.

**U4 — Lighting extremes.** Direct outdoor sun / strong backlight (walking toward a bright
exit) vs dim indoor corners. Watch for confidence collapse (missed real objects) or
flicker. Note conditions where the detector struggles.

**U5 — Group moving as one.** A family or tour group walking together. Does it read as a
head-turn (collective motion) and over-suppress? Does "multiple" fire sensibly? Does one
person hog the spotlight?

**U6 — Quiet fast vehicles.** E-scooters / bikes on a shared path — fast, near-silent, and
a real hazard. Combine U1 + W2 observations; strong motivation for the approach term and
for `URGENT_CLASSES` membership.

**U7 — Audibility in noise.** In a genuinely loud mall/street, **can the tester even hear
the announcements** over ambient noise (bone-conduction vs the environment)? Not a code
parameter, but a real-world UX finding — note volume/clarity limits and whether long
phrases get lost.

**U8 — Track-ID churn under occlusion.** People repeatedly passing behind pillars/each
other. Watch for the same object being re-announced as "new," or stale state leaking. Ties
to `STALE_TRACK_FRAMES` and the tracker settings in `app.py`.

---

## 6. Per-run log template

Copy one block per scenario run:

```
Scenario: ____   Location: ____   Date/time: ____   Testers/spotter: ____
Params changed since last run: ____ (one at a time!)
What the scene contained: ____
What it announced (from log): ____
Layering observed? (Y/N): ____
Missed anything important? What: ____
Over-talked / under-talked? ____
Urgent/preemption behaved? ____
Subjective feel (1 calm – 5 overwhelming): ____
Next parameter to try: ____
```

Bring the filled logs back and update `src/second_vision/core/priority.py` (and the
`callbacks.py` constants) accordingly. Record the settled values and the reasoning in
`.agents/handoff_v3.md` so the next session knows why each number is what it is.

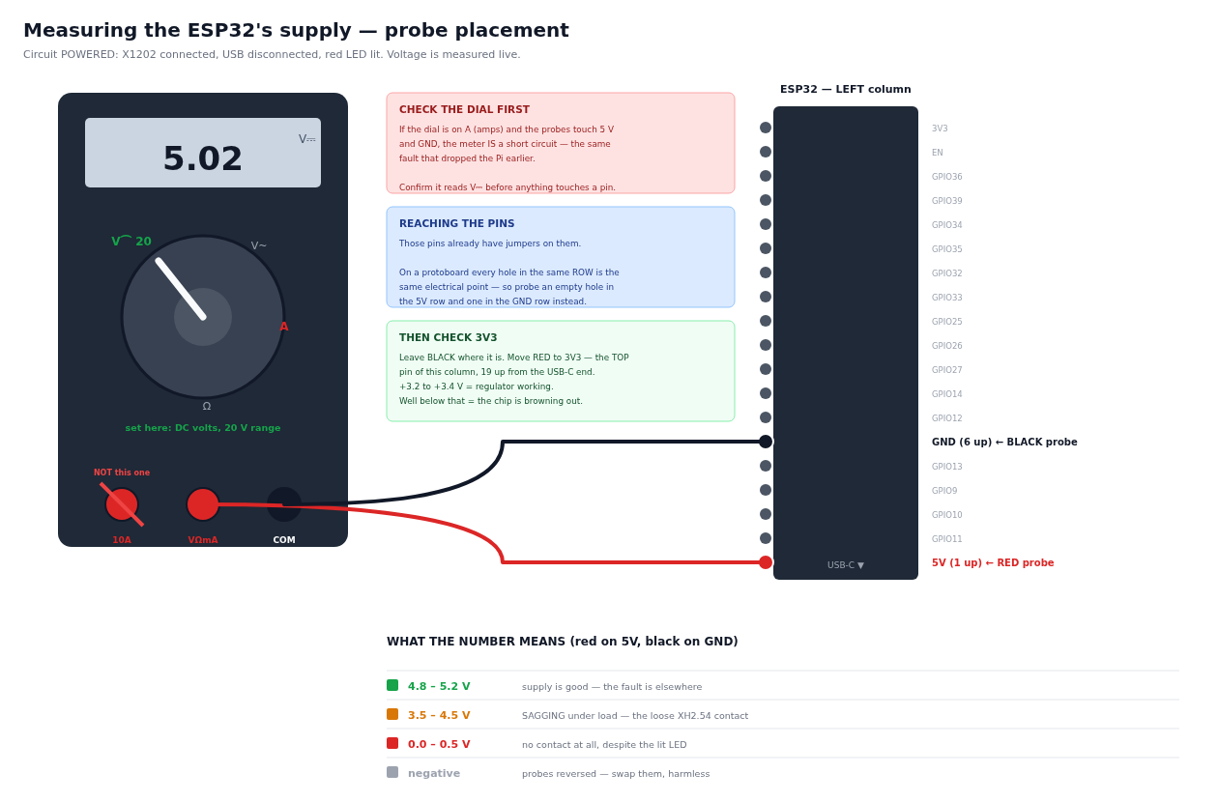
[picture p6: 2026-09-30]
firmware/control-panel/docs/measure_points.png

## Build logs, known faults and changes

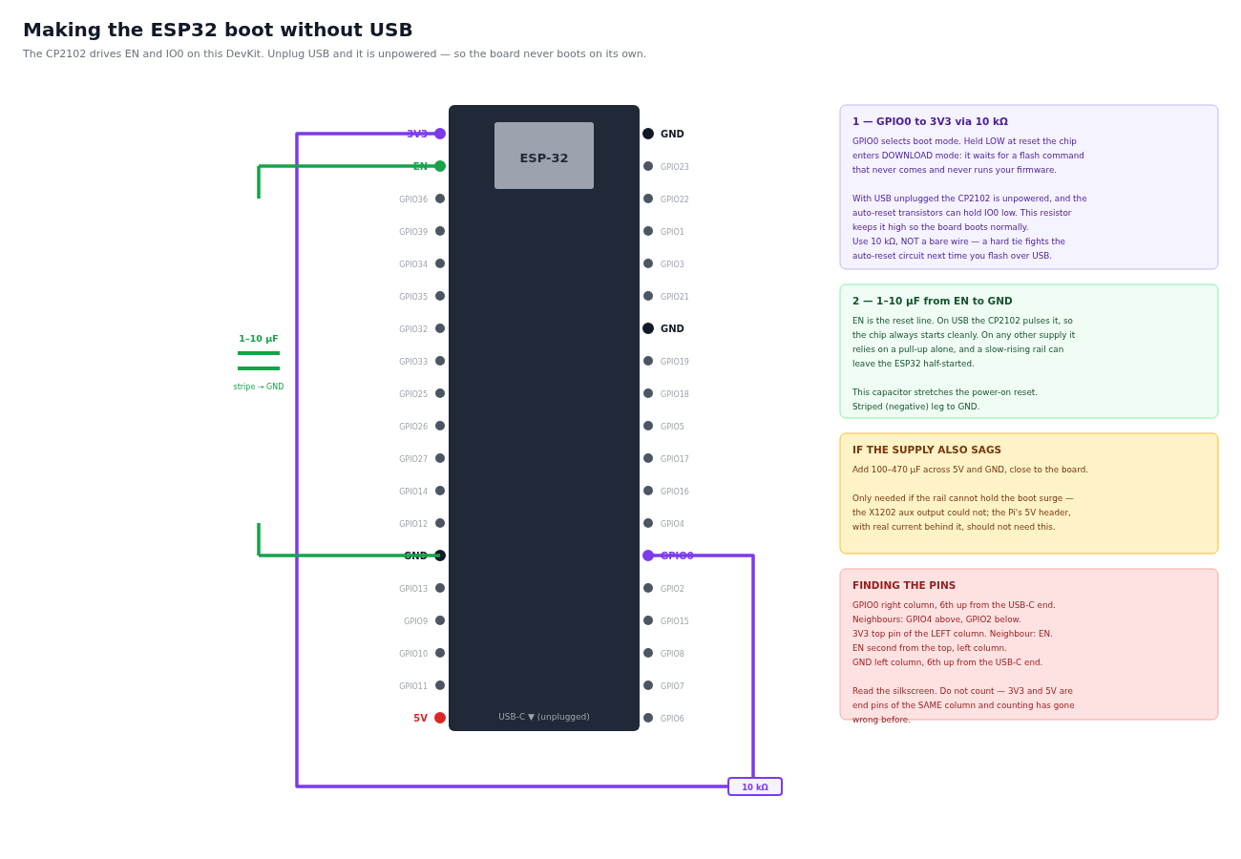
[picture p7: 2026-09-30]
firmware/control-panel/docs/standalone_fix.png

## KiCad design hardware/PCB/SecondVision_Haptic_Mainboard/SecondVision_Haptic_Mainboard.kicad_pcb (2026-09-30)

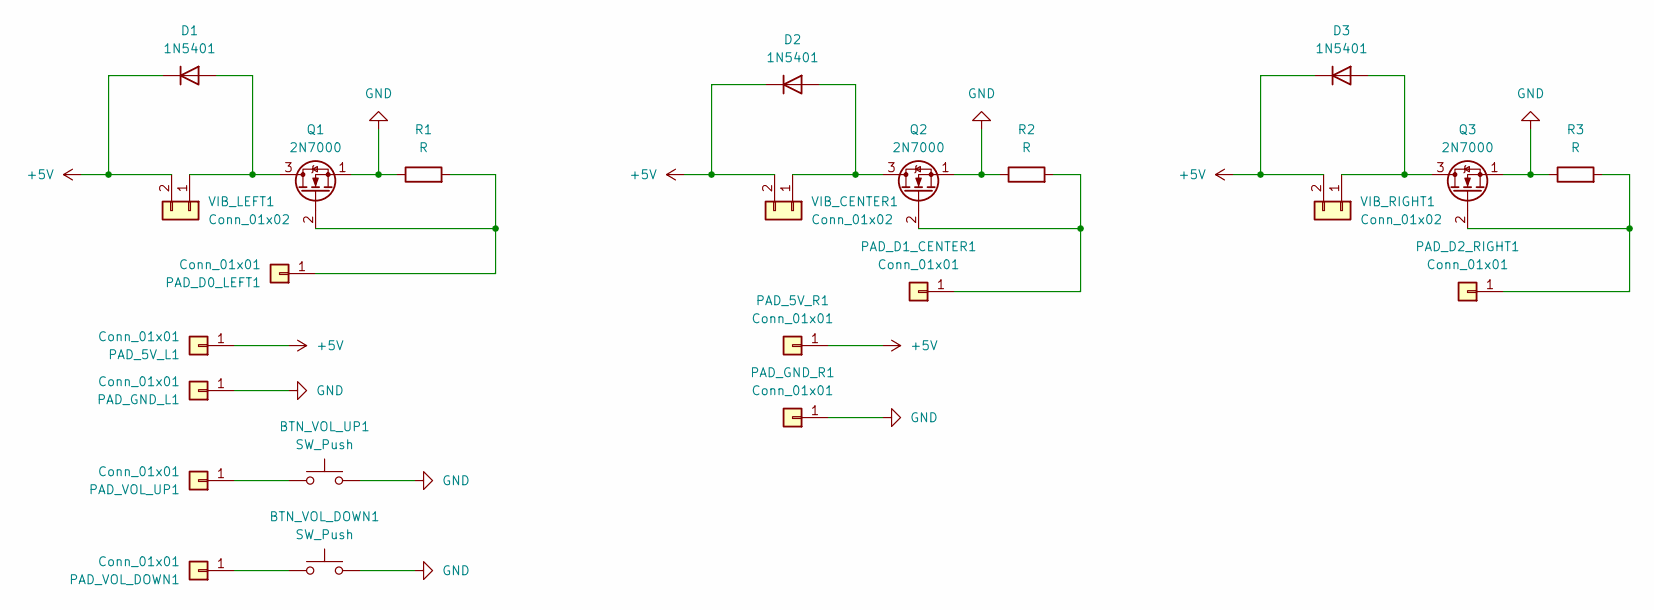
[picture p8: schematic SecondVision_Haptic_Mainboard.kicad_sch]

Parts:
BTN_VOL_DOWN1: SW_Push; SW_SPST_B3U-1000P
BTN_VOL_UP1: SW_Push; SW_SPST_B3U-1000P
D1, D2, D3: 1N5401; D_SOD-123
PAD_5V_L1, PAD_5V_R1: Conn_01x01; PinHeader_1x01_P2.54mm_Vertical
PAD_D0_LEFT1, PAD_D1_CENTER1, PAD_D2_RIGHT1: Conn_01x01; PinHeader_1x01_P2.54mm_Vertical
PAD_GND_L1: Conn_01x01; PinHeader_1x01_P2.54mm_Vertical
PAD_GND_R1: Conn_01x01; PinHeader_1x01_P2.54mm_Vertical
PAD_VOL_DOWN1: Conn_01x01; PinHeader_1x01_P2.54mm_Vertical
PAD_VOL_UP1: Conn_01x01; PinHeader_1x01_P2.54mm_Vertical
Q1, Q2, Q3: 2N7000; SOT-23
R1, R2, R3: R; R_0603_1608Metric
VIB_CENTER1: Conn_01x02; PinHeader_1x02_P2.54mm_Vertical
VIB_LEFT1: Conn_01x02; PinHeader_1x02_P2.54mm_Vertical
VIB_RIGHT1: Conn_01x02; PinHeader_1x02_P2.54mm_Vertical

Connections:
+5V: D1.1 (K), D2.1 (K), D3.1 (K), PAD_5V_L1.1 (Pin_1_1), PAD_5V_R1.1 (Pin_1_1), VIB_CENTER1.2, VIB_LEFT1.2, VIB_RIGHT1.2
GND: BTN_VOL_DOWN1.2, BTN_VOL_UP1.2, PAD_GND_L1.1 (Pin_1_1), PAD_GND_R1.1 (Pin_1_1), Q1.1 (S), Q2.1 (S), Q3.1 (S), R1.1, R2.1, R3.1
unnamed: D1.2 (A), Q1.3 (D), VIB_LEFT1.1
unnamed: D2.2 (A), Q2.3 (D), VIB_CENTER1.1
unnamed: D3.2 (A), Q3.3 (D), VIB_RIGHT1.1
unnamed: PAD_D0_LEFT1.1 (Pin_1_1), Q1.2 (G), R1.2
unnamed: PAD_D1_CENTER1.1 (Pin_1_1), Q2.2 (G), R2.2
unnamed: PAD_D2_RIGHT1.1 (Pin_1_1), Q3.2 (G), R3.2
unnamed: BTN_VOL_DOWN1.1, PAD_VOL_DOWN1.1 (Pin_1_1)
unnamed: BTN_VOL_UP1.1, PAD_VOL_UP1.1 (Pin_1_1)

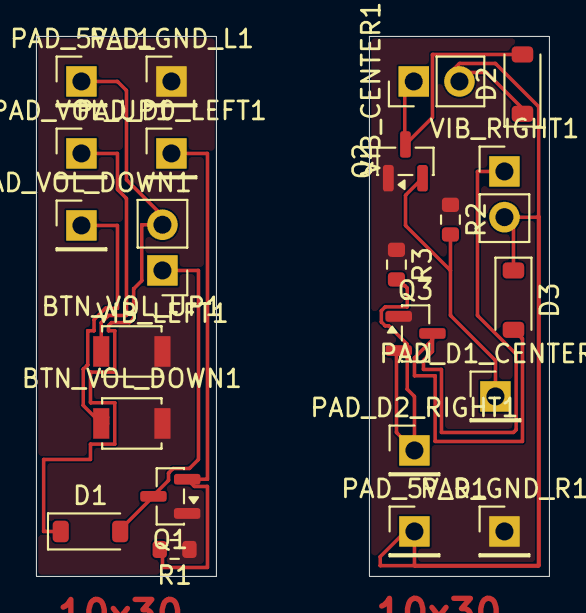
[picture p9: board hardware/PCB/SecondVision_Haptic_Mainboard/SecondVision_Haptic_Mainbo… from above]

Board: 2 copper layers, 28.5 x 30.0 mm, 23 parts (0 on the bottom side), 10 nets.

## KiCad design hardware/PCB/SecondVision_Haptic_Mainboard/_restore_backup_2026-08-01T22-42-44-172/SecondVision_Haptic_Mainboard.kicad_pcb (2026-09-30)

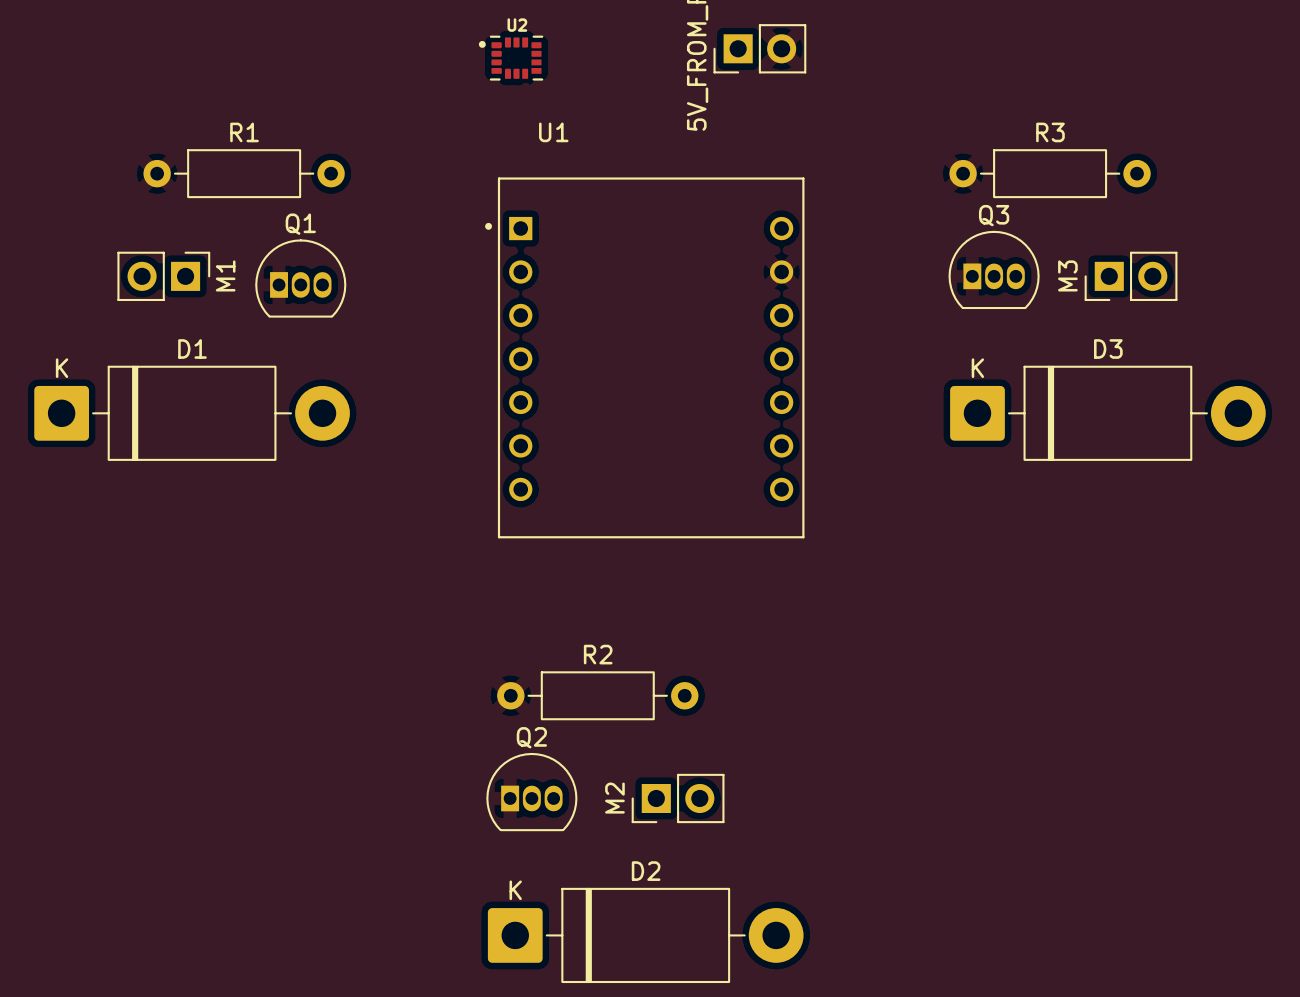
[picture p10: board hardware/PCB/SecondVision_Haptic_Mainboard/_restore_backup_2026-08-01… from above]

Board: 2 copper layers, 15 parts (0 on the bottom side), 11 nets, no tracks yet.

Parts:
5V_FROM_PI1: Conn_01x02; PinHeader_1x02_P2.54mm_Vertical
D1, D2, D3: 1N5401; D_DO-201AD_P15.24mm_Horizontal
M1, M2, M3: Motor_DC; PinHeader_1x02_P2.54mm_Vertical
Q1, Q2, Q3: 2N7000; TO-92_Inline
R1, R2, R3: R; R_Axial_DIN0207_L6.3mm_D2.5mm_P10.16mm_Horizontal
U1: XIAO_ESP32C3; MODULE_XIAO_ESP32C3
U2: BMI160; PQFN50P250X300X88-14N

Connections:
+3.3V: U1.12 (VCC_3V3), U2.8 (VDD)
+5V: 5V_FROM_PI1.1, D1.1 (K), D2.1 (K), D3.1 (K), M1.1 (+), M2.1 (+), M3.1 (+), U1.14 (VUSB)
GND: 5V_FROM_PI1.2, Q1.1 (S), Q2.1 (S), Q3.1 (S), R1.1, R2.1, R3.1, U1.13 (GND), U2.7 (GND)
unnamed: D1.2 (A), M1.2 (-), Q1.3 (D)
unnamed: D2.2 (A), M2.2 (-), Q2.3 (D)
unnamed: D3.2 (A), M3.2 (-), Q3.3 (D)
unnamed: Q1.2 (G), R1.2, U1.1 (D0)
unnamed: Q2.2 (G), R2.2, U1.2 (D1)
unnamed: Q3.2 (G), R3.2, U1.3 (D2)
unnamed: U1.5 (D4), U2.14 (SDX)
unnamed: U1.6 (D5), U2.13 (SCX)

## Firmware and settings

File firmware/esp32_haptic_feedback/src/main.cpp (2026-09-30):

#include <Arduino.h>
#include <ArduinoJson.h>
#include <Wire.h>
#include <DFRobot_BMI160.h>
#include <math.h>

// --- CONFIGURATION & MODES ---
// Set to true for MAC / Standalone testing (cycles incremental test vibrations)
// Set to false for Deployment mode (listens for binary UART packets from the
// Raspberry Pi 5 on the dedicated PiSerial link, see below)
bool MAC_MODE = false;

// --- Pins for the Motors (Using XIAO ESP32-C3 mappings) ---
const int leftMotorPin = D0;
const int centerMotorPin = D1;
const int rightMotorPin = D2;

// --- UART link to the Raspberry Pi (XIAO ESP32-C3) ---
// D6 (TX) / D7 (RX) map to GPIO21 / GPIO20 on this board — confirmed wiring,
// not the default USB debug port. The ESP32-C3's UART peripherals are
// GPIO-matrix-routable, so binding UART1 to these two pins is a config
// choice, not a fixed-function requirement; it keeps the Pi link off `Serial`
// (native USB CDC) entirely, so debug prints never collide with command bytes
// the way they would if both shared one port.
#define PI_TX_PIN D6
#define PI_RX_PIN D7
HardwareSerial PiSerial(1);

// --- Wire protocol (matches src/second_vision/workers/serial_worker.py) ---
// Every packet starts with 0xAA. The byte after that selects the type, which
// fixes how many bytes follow it:
//
//   0x01  motor update   left, center, right         + 1 checksum byte
//   0x04  hazard alert   severity, pattern            + 1 checksum byte
//   0xFE  heartbeat      (no payload)                 + 1 checksum byte
//
// checksum = msgType XOR every payload byte (0 payload bytes for heartbeat,
// so its checksum is just 0xFE). The board answers every *valid* packet with
// 0xAA 0xFF <msgType> — that 2-byte prefix is what serial_worker.py scans for.
const uint8_t START_BYTE = 0xAA;
const uint8_t ACK_TYPE = 0xFF;
const uint8_t MSG_MOTOR_UPDATE = 0x01;
const uint8_t MSG_IMU_TELEMETRY = 0x02;  // ESP32 -> Pi, no ACK expected back
const uint8_t MSG_TURN_EVENT = 0x03;     // ESP32 -> Pi, no ACK — see sendTurnEvent()
const uint8_t MSG_HAZARD_ALERT = 0x04;
const uint8_t MSG_HEARTBEAT = 0xFE;

const uint8_t MOTOR_UPDATE_PAYLOAD_LEN = 3;  // left, center, right
const uint8_t HAZARD_ALERT_PAYLOAD_LEN = 2;  // severity, pattern

// 0x02's `state` byte. Only NORMAL is ever produced now — the BMI160 moved
// from the glasses to the sling bag, so the old head_moving/wrong_pitch
// classification (gyroYaw/accelPitch thresholds tuned for a head-mounted
// sensor) no longer means anything and has been removed. The constant stays
// because 0x02's wire format is frozen as-shipped and still needs a value
// here; the Pi-side IMU_STATE_NAMES mapping is unchanged and still contains
// the now-dead 1/2 entries for the same reason.
const uint8_t IMU_STATE_NORMAL = 0;

// A packet that stops arriving mid-way (cable pulled, Pi crashed while
// writing) must not wedge the reader forever waiting for bytes that are never
// coming. Anything slower than this between bytes of the SAME packet is
// treated as a dead packet, and the reader resyncs on the next 0xAA.
const unsigned long BYTE_TIMEOUT_MS = 50;

// The Pi treats >2.5 s of no ACK as the board being gone (ACK_TIMEOUT_SECONDS
// in serial_worker.py) and stops trusting the link. Symmetrically, the board
// must not keep the motors running on a command the Pi sent a long time ago —
// mirrors the "ESP32 zeroes the motors after 3 s without traffic" contract
// serial_worker.py's heartbeat comment documents.
const unsigned long WATCHDOG_TIMEOUT_MS = 3000;

// How long a hazard alert overrides the per-zone motor duty before the last
// known-good motor update is restored. Short and blunt on purpose — a ground
// hazard is meant to read as distinct from the continuous per-zone channel,
// not as a fourth intensity level on it.
const unsigned long HAZARD_PULSE_MS = 150;

// --- Reader state machine ---
enum ReadState {
  WAIT_START,
  WAIT_TYPE,
  READ_PAYLOAD,
  READ_CHECKSUM,
};

ReadState readState = WAIT_START;
uint8_t currentType = 0;
uint8_t packetPayload[MOTOR_UPDATE_PAYLOAD_LEN];
uint8_t payloadLen = 0;
uint8_t payloadIndex = 0;
unsigned long lastByteAt = 0;

// --- Motor state (shared with DEPLOYMENT mode's binary receiver) ---
uint8_t motorDuty[3] = {0, 0, 0};  // left, center, right — last valid update
unsigned long lastPacketAt = 0;
bool motorsZeroed = true;  // starts true: nothing commanded yet

bool hazardActive = false;
unsigned long hazardEndsAt = 0;

// --- SAFETY FEATURE: Hardware Governor ---
// Raised to 255 (100% full power) to maximize vibration intensity
const int MAX_PWM = 255;

DFRobot_BMI160 bmi160;
unsigned long lastSensorTime = 0;
const int sensorInterval = 200;

// --- INCREMENTAL PULSE VARIABLES (MAC MODE) ---
unsigned long lastFadeTime = 0;
const int fadeInterval = 50; // Increases PWM every 50ms
int currentPWM = 0;
const int fadeStep = 15;     // How much the power increases per step

bool imuHealthy = false;

void applyMotorDuty(uint8_t left, uint8_t center, uint8_t right) {
  analogWrite(leftMotorPin, left);
  analogWrite(centerMotorPin, center);
  analogWrite(rightMotorPin, right);
}

void sendAck(uint8_t msgType) {
  uint8_t ackPacket[] = {START_BYTE, ACK_TYPE, msgType};
  PiSerial.write(ackPacket, sizeof(ackPacket));
}

// Outbound ESP32 -> Pi. Big-endian (high byte first) for the two int16
// fields, matching typical wire-protocol convention; the Pi-side parser must
// agree on this byte order. No ACK is expected back for this message type —
// unlike the inbound motor/hazard/heartbeat packets, nothing on the ESP32
// currently needs to know the Pi received it.
void sendImuTelemetry(uint8_t state, int16_t rawPitch, int16_t rawYaw) {
  uint8_t pitchHi = (uint8_t)((rawPitch >> 8) & 0xFF);
  uint8_t pitchLo = (uint8_t)(rawPitch & 0xFF);
  uint8_t yawHi = (uint8_t)((rawYaw >> 8) & 0xFF);
  uint8_t yawLo = (uint8_t)(rawYaw & 0xFF);
  uint8_t checksum = MSG_IMU_TELEMETRY ^ state ^ pitchHi ^ pitchLo ^ yawHi ^ yawLo;

  uint8_t packet[] = {START_BYTE, MSG_IMU_TELEMETRY, state,
                       pitchHi, pitchLo, yawHi, yawLo, checksum};
  PiSerial.write(packet, sizeof(packet));
}

// --- Turn event: 0x03, ESP32 -> Pi, no ACK ---
// Wire format (deliberately leaner than 0x02 — this is a discrete event, not
// continuous telemetry, so it carries only what a fired event needs):
//
//   byte 0   0xAA start
//   byte 1   0x03 (MSG_TURN_EVENT)
//   byte 2-3 delta_deg, int16, big-endian, signed — accumulated rotation
//            since the last event, in degrees, sign = rotation direction
//   byte 4   checksum = 0x03 ^ delta_hi ^ delta_lo
//
// Signed-degrees was chosen over a separate "direction byte" (left/right)
// because the sign's real-world meaning depends on how the sensor ended up
// mounted — a signed value carries the same information without committing
// to a left/right label. Bench-confirmed across 7+ test rounds: right turns
// produce negative values, left turns positive, for this mounting.
void sendTurnEvent(int16_t deltaDeg) {
  uint8_t hi = (uint8_t)((deltaDeg >> 8) & 0xFF);
  uint8_t lo = (uint8_t)(deltaDeg & 0xFF);
  uint8_t checksum = MSG_TURN_EVENT ^ hi ^ lo;
  uint8_t packet[] = {START_BYTE, MSG_TURN_EVENT, hi, lo, checksum};
  PiSerial.write(packet, sizeof(packet));
}

// --- Turn detection: gyro-X (torso yaw) integrated to a threshold, then
// reported as one event and reset. Same accumulate-until-threshold-then-reset
// shape as HazardDebouncer (src/second_vision/core/depth_utils.py), adapted
// to this file's existing globals-and-functions style rather than a class,
// since nothing else here is object-oriented.
//
// UPDATED after a physical remounting: gyro-Z was the original assumed yaw
// axis, but axis-verification bench testing (all three raw axes logged
// during real body turns) showed gyro-Z capturing only a small fraction of
// real rotation. After remounting, gyro-X shows a large, sustained,
// consistent-sign signal during real turns (gyro-Y is noisy and crosses
// zero) — gyro-X is now the axis that measures body yaw rate for this
// mounting. As with the original Z assumption, this is a mounting-derived
// conclusion, not something verifiable from code, and should be reconfirmed
// if the sensor is remounted again.

// BMI160 default gyro range is +-2000 dps (set in the library's I2cInit,
// unchanged by this file) => 32768 / 2000 = 16.384 LSB per deg/s. Converting
// to real degrees before integrating means the thresholds below are tunable
// in physically meaningful units, not sensor-specific raw counts.
const float GYRO_LSB_PER_DPS = 16.384f;

// BMI160 default accel range is +-2g (also set in I2cInit, also unchanged)
// => 32768 / 2 = 16384 LSB per g. Used by the accel-corroboration check
// below, not by the gyro integration above.
const float ACCEL_LSB_PER_G = 16384.0f;

// Below this rate, treat the sensor as not turning — keeps stationary noise
// from slowly accumulating into a false event over many samples. Same
// "silence is the correct resting state" principle as haptics.py's DEADBAND.
// PLACEHOLDER — reasoned, not measured against the real sensor/mount. Not
// changed for the sample-rate fix below: this is a RATE threshold (deg/s),
// a physical property of the sensor reading itself, not something that
// should shift just because it is now checked more often.
const float TURN_RATE_DEADBAND_DPS = 8.0f;

// Accumulated rotation needed before a turn event fires.
// PLACEHOLDER — "roughly a quarter turn", not tuned against a real wearer.
// Not changed for the sample-rate fix below either: the fix restores
// integration ACCURACY (a real 90 deg turn should now accumulate close to
// 90 deg instead of ~10 deg), so 45 deg remains a sensible "about a quarter
// turn" trigger. Changing this number to compensate for the old undercount
// bug would double-count the fix.
const float TURN_EVENT_THRESHOLD_DEG = 45.0f;

// After firing, further accumulation is ignored for this long, so one
// continuous turn past the threshold doesn't fire repeated events.
// PLACEHOLDER — not tuned. Independent of sample rate (this gates TIME
// between fired events, not integration granularity).
const unsigned long TURN_EVENT_COOLDOWN_MS = 500;

// --- Peak-tracking + settle-detection (replaces the old signed-net-sum,
// fire-on-threshold-crossing design) ---
//
// WHY: extensive bench testing (marker-button-timestamped turns, full
// per-sample raw logging with hand-verified running-total arithmetic, a
// parallel no-deadband accumulator, and the live production accumulator
// exposed in a periodic diagnostic report — all temporary tooling, since
// removed once this investigation concluded) confirmed sampling rate, the
// dt-clamp, the summation arithmetic, the deadband, and the raw gyro sign
// convention were all working correctly — and STILL only ~13-17% of a real
// 90/180 degree body turn was ever reported. Root cause: a real turn shows
// a clean gyro peak, reliably followed by real counter-rotation as the
// body naturally settles right after completing the turn (ordinary human
// movement, not sensor error). Because the OLD total was a plain SIGNED
// running sum, that settle motion subtracted from the peak, cancelling out
// most of the real turn by the time the value was read.
//
// FIX: track the signed PEAK deviation reached (immune to what happens
// after it), and separately detect when the turn has SETTLED — rate has
// stayed within the deadband continuously for TURN_SETTLE_DURATION_MS.
// Report the tracked PEAK (not the running total) once settled, then reset
// both for the next turn. A MAX_TURN_DURATION_MS failsafe forces the same
// finalize even without a clean settle, so a turn that never quiets down
// (continuous slow rotation, spinning in place) cannot hold state open
// indefinitely.

// How long the rate must stay continuously within TURN_RATE_DEADBAND_DPS
// before a turn counts as complete. PLACEHOLDER — unmeasured. Reasoning:
// too short risks calling a brief mid-turn pause (a hitch between strides)
// "done" — but since the report uses the tracked PEAK rather than the
// running total, firing early mostly means reporting a peak that hasn't
// finished growing yet (undercounting), not contaminating it with reverse
// motion, which is a milder failure mode than the old design's. Too long
// delays the haptic feedback the wearer would feel. 300ms is chosen as
// comfortably longer than a single slow/dropped sample (~28ms at the
// ~35Hz actual fast-tick rate) while staying well under a natural pause
// between separate movements.
const unsigned long TURN_SETTLE_DURATION_MS = 300;

// No-settle failsafe: if motion never returns to the deadband continuously
// for TURN_SETTLE_DURATION_MS, force a finalize (report the peak so far, if
// significant) once this much time has elapsed since motion started.
// PLACEHOLDER — unmeasured. 4s is generous versus a typical real turn
// (well under 1.5s even for a slow 180), while still bounding the worst
// case (a wearer spinning continuously) to a few seconds of latency rather
// than holding state open forever.
const unsigned long MAX_TURN_DURATION_MS = 4000;

// --- Fast-rate sampling for the turn detector ---
// Deliberately INDEPENDENT of sensorInterval (200ms) above, which stays
// untouched — 0x02's cadence, wire format and every other behavior around
// it are frozen per this project's scope discipline. This is a second,
// separate millis()-based tick, with its own I2C read, used ONLY by the
// turn detector.
//
// Bench-measured on real hardware: at 200ms/5Hz, a real 90 deg turn only
// accumulated ~10 deg (~11%), and a real 180 deg turn only ~30 deg (~16%) —
// most of a body turn's rotation happens BETWEEN samples at that rate.
// 25ms (40Hz) gives roughly 20 samples across a half-second turn, which
// should capture the great majority of the motion.
//
// Why 25ms is affordable in loop(): this tick does one I2C read (a BMI160
// register burst read over I2C is sub-millisecond at typical bus speeds)
// plus a handful of float multiplies — no Serial printing and no PiSerial
// write unless an event actually fires, which bench data shows is rare.
// The EXISTING 200ms block's Serial.print/serializeJson calls (USB CDC,
// string formatting) are a heavier per-tick cost than this whole function,
// and that block already runs fine inside the same loop(). pollPiSerial()
// runs every loop() iteration regardless and only does work when bytes are
// actually waiting, so a lean 40Hz addition alongside it should not starve
// UART receiving or motor-command responsiveness — flagging this as
// reasoned, not bench-measured against actual loop() timing.
const unsigned long TURN_SAMPLE_INTERVAL_MS = 25;
unsigned long lastTurnSampleTickAt = 0;

// A tick whose dt comes out far larger than TURN_SAMPLE_INTERVAL_MS (e.g. a
// stalled loop() iteration from something else taking too long) would
// integrate an inflated rotation guess at the last-known rate over that
// whole gap. Any tick with dt beyond this is DISCARDED, not clamped: there
// is no way to know what actually happened during a gap this large, and
// integrating a guess is worse than skipping the sample. This is the
// previously-flagged, not-yet-implemented dt-clamp gap, now closed.
const float MAX_TURN_DT_SECONDS = 0.1f;  // 4x the intended tick interval
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
void loop() {
  unsigned long currentMillis = millis();

  // =================================================================
  // MODE 1: MAC MODE (Incremental Power: Low to High, then Loop)
  // =================================================================
  if (MAC_MODE) {
    if (currentMillis - lastFadeTime >= fadeInterval) {
      lastFadeTime = currentMillis;
      
      // Apply current power to all motors
      analogWrite(leftMotorPin, currentPWM);
      analogWrite(centerMotorPin, currentPWM);
      analogWrite(rightMotorPin, currentPWM);
      
      Serial.printf("[MAC MODE] Motors vibrating at PWM: %d\n", currentPWM);
      
      // Increment power
      currentPWM += fadeStep;
      
      // Loop back to low once it exceeds maximum power
      if (currentPWM > MAX_PWM) {
        currentPWM = 0; 
        Serial.println("[MAC MODE] --- Max power reached. Looping back to 0 ---");
      }
    }
  } 
  // =================================================================
  // MODE 2: DEPLOYMENT MODE (Connected to RPi5 via PiSerial, D6/D7)
  // =================================================================
  // Binary protocol matching src/second_vision/workers/serial_worker.py —
  // see the packet definitions and pollPiSerial() above. Motor duty arrives
  // pre-shaped (0-255) from the Pi's HapticMapper; this stage applies it
  // as-is and does not add its own curve or floor.
  else {
    pollPiSerial();
    applyHazardExpiry();
    applyWatchdog();
  }

  // =================================================================
  // FAST TURN-DETECTOR SAMPLING (independent of the 200ms 0x02 tick below)
  // =================================================================
  // See TURN_SAMPLE_INTERVAL_MS above for why this needs to run faster than
  // sensorInterval — at 200ms the detector badly undercounted real turns
  // (bench-confirmed). This tick does its own I2C read and touches nothing
  // 0x02/brownout-related: imuHealthy is only ever SET by the slower block
  // below, this one only reads it, and a failed read here is simply
  // skipped rather than acted on — the slower block's own brownout check
  // remains the sole owner of reboot decisions.
  if (currentMillis - lastTurnSampleTickAt >= TURN_SAMPLE_INTERVAL_MS) {
    lastTurnSampleTickAt = currentMillis;

    if (imuHealthy) {
      int16_t turnSensorData[6] = {0};
      if (bmi160.getAccelGyroData(turnSensorData) == 0) {
        // gx = gyro-X, the yaw axis that now drives production turn
        // detection — see the axis note above updateTurnDetector().
        int16_t gx = turnSensorData[0];
        int16_t ax = turnSensorData[3];
        int16_t ay = turnSensorData[4];
        int16_t az = turnSensorData[5];

        // 0x03 turn event: torso yaw (gyro X — see the axis note above
        // updateTurnDetector()) peak-tracked since the last reset, reported
        // once the rate has settled back within the deadband for
        // TURN_SETTLE_DURATION_MS (or the no-settle failsafe forces it),
        // corroborated by accel magnitude, then reset. Sent ONLY when an
        // event fires — this is a discrete-event channel, not continuous
        // telemetry like 0x02.
        TurnEvent turn = updateTurnDetector(gx, ax, ay, az, currentMillis);
        if (turn.fired) {
          int16_t deltaDeg = (int16_t)lroundf(turn.deltaDeg);
          sendTurnEvent(deltaDeg);
          // Sign convention bench-confirmed across 7+ test rounds: right
          // turns produce negative values, left turns positive.
          Serial.printf("[TURN EVENT] %d deg (peak, settle-triggered)\n", deltaDeg);
        }
      }
    }
  }

  // =================================================================
  // SENSOR READING & WALKING TOLERANCE (IMU Telemetry)
  // =================================================================
  if (currentMillis - lastSensorTime >= sensorInterval) {
    lastSensorTime = currentMillis; 

    if (imuHealthy) {
      int16_t sensorData[6] = {0};
      if(bmi160.getAccelGyroData(sensorData) == 0) {
        int16_t gyroYaw = sensorData[2];
        // Read only to keep feeding 0x02's unchanged wire format below — the
        // sensor is torso-mounted now, so this is no longer meaningfully
        // "pitch" for anything; nothing in this file classifies it anymore.
        int16_t rawAccelY = sensorData[4];

        // --- SELF-HEALING BROWNOUT RECOVERY ---
        // Unrelated to the retired head-mounted classification — a true
        // sensor/I2C fault plausibly zeroes every axis, so this stays as a
        // generic "did the whole IMU return garbage" check.
        if (gyroYaw == 0 && rawAccelY == 0) {
          Serial.println("[WARNING] SENSOR BROWNOUT DETECTED. REBOOTING IMU...");
          imuHealthy = (bmi160.I2cInit(0x69) == 0);
          return;
        }

        // 0x02 telemetry: wire format, field meanings and cadence (every
        // tick, both modes) all unchanged. `state` is hardcoded to NORMAL —
        // see the IMU_STATE_NORMAL comment above for why.
        sendImuTelemetry(IMU_STATE_NORMAL, rawAccelY, gyroYaw);

        JsonDocument outDoc;
        outDoc["state"] = "normal";
        outDoc["raw_pitch"] = rawAccelY;
        outDoc["raw_yaw"] = gyroYaw;

        Serial.print("[IMU TELEMETRY] ");
        serializeJson(outDoc, Serial);
        Serial.println();
      } else {
        imuHealthy = false;
        Serial.println("[ERROR] Lost connection to BMI160 IMU! Telemetry suspended.");
      }
    }
  }
}

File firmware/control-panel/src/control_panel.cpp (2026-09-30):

/*
 * Second Vision — physical control panel (ESP32-WROOM-32, 38-pin DevKit)
 *
 * Speaks PROTOCOL v1 (see PROTOCOL.md). One-way, ESP32 -> Pi, 9600 8N1,
 * lines terminated with '\n' only, 64 bytes max:
 *
 *   V:panel:<n>       protocol version, boot only
 *   S:<key>:<value>   setting
 *   M:<mode>          detection | depth | both | none
 *   B:<name>          event
 *
 * TWO LATCHING ROCKERS, one per capability. Each owns a model AND the output
 * channel that model feeds, because a model with no way to reach the user is
 * just heat:
 *
 *   DETECT rocker  ->  YOLOv8 object detection  +  speech   (tts_enabled)
 *   DEPTH  rocker  ->  SC-DepthV3 depth         +  motors   (vibration_enabled)
 *
 * Wiring: docs/breadboard_wiring.svg (controls) and docs/pi_link_wiring.svg
 * (link to the Pi, powered from the X1202 UPS).
 */
#include <Arduino.h>
#include <stdarg.h>

/*
 * NO_BROWNOUT: for running off a supply with no bulk capacitance behind it.
 *
 * The ESP32 pulls a current spike as it boots. On USB that is absorbed by the
 * host's capacitance; on a bare jumper from a header pin the rail dips, the
 * brownout detector fires, and the chip dies partway through setup() — UART
 * already initialised (TX idles high) but nothing ever transmitted.
 *
 * This disables that detector. Running slightly under-volt is survivable;
 * never finishing setup() is not.
 *
 * ONE change only. An earlier attempt also called setCpuFrequencyMhz(80) to
 * halve the current — do NOT do that: the UART divisor comes off the system
 * clock, so changing it around Serial.begin() corrupts every line at both ends.
 */
#ifndef NO_BROWNOUT
#  define NO_BROWNOUT 0
#endif
#if NO_BROWNOUT
#  include "soc/soc.h"
#  include "soc/rtc_cntl_reg.h"
#endif

const uint32_t BAUD = 9600;
const uint8_t  PROTOCOL_VERSION = 1;
const uint16_t DEBOUNCE_MS = 50;     // generous — the rockers' contacts need it
const size_t   MAX_LINE    = 64;     // protocol cap, enforced in emit()

/*
 * The link to the Pi is UART2 with TX remapped to GPIO23 — deliberately NOT
 * UART0. UART0 is the USB serial, and the ROM bootloader dumps its 115200 log
 * there on every reset; on a shared UART that garbage lands in the Pi's parser.
 * On its own UART the Pi never sees it, and USB stays free for flashing and
 * monitoring at the same time.
 *
 * RX is unused. The panel never reads — a reverse channel is a version bump.
 */
const int8_t PIN_LINK_TX = 23;
const int8_t PIN_LINK_RX = -1;
#define LINK Serial2

/*
 * Panel and Pi share the X1202, so they power up together and the Pi is ~30 s
 * from opening the port. A one-shot report at boot would be lost, leaving
 * SystemConfig disagreeing with switches the user can see and feel. So the
 * whole state is re-announced on this timer, forever: it survives the boot
 * race, a dropped byte, and any restart of main.py while the panel stays
 * powered — the common case in development.
 *
 * Safe ONLY because config_reader.py acts on CHANGES. An unconditional reader
 * would rebuild the Hailo pipeline on every one of these.
 */
const uint32_t HEARTBEAT_MS = 10000;

struct Input {
  uint8_t pin;
  bool activeLow;
  int stable;
  int lastRead;
  uint32_t changedAt;
};

/*
 * Pin choice is a safety property, not a preference. GPIO17 and GPIO18 both sit
 * with plain GPIOs either side of them (GPIO5/GPIO16 and GPIO19/GPIO5), so a
 * jumper one hole off reads wrong instead of shorting. GPIO23 is NOT safe for a
 * switch — it is one row from the GND pin, on a row that carries 3V3 on the
 * opposite side of the board — which is why it carries the single soldered link
 * wire and nothing else.
 */
//                  pin  activeLow
Input detect  = { 17,  true,  HIGH, HIGH, 0 };   // rocker — LATCHING — detection + TTS
Input depth   = { 18,  true,  HIGH, HIGH, 0 };   // rocker — LATCHING — depth + motors
Input statBtn = { 22,  true,  HIGH, HIGH, 0 };   // tactile button

/*
 * HAVE_POT=0 omits the potentiometer entirely — no reads, no S:motor_strength.
 *
 * This is not a convenience flag. GPIO34 is input-only with NO internal pull-up
 * (correct for a pot, and on ADC1 so it survives WiFi being switched on; ADC2
 * would not). Unconnected, it FLOATS, and the 80-count deadband — sized for a
 * wired pot's dither — is exceeded constantly.
 *
 * Measured on a bare board: ~1,625 spurious S:motor_strength lines in 30 s,
 * about 54/s, at 22 bytes each on both transports. Against a 960 B/s budget at
 * 9600 baud that leaves emit() blocking almost continuously. Heartbeats and
 * rocker events still got through, but on the Pi that noise competes with the
 * pipeline for the link.
 *
 * A grounding jumper on GPIO34 fixes it too, but a jumper is a thing to
 * remember and a build flag is not.
 */
#ifndef HAVE_POT
#  define HAVE_POT 1
#endif

#if HAVE_POT
// Input-only pin, no internal pull-up — correct for a pot, and it is on ADC1,
// which keeps working if WiFi is ever switched on. ADC2 would not.
const uint8_t PIN_KNOB = 34;                     // B10K wiper
#endif

#if HAVE_POT
// Hysteresis-filtered knob reading, shared by the pot handler and the state
// burst. The burst must resend the SETTLED value, not a fresh analogRead():
// the ADC's last bits dither, and a raw read would flip the %.2f output between
// neighbouring values and look like a change on every heartbeat.
int lastRaw = -1000;
#endif

bool isOn(const Input &in) {
  return in.activeLow ? in.stable == LOW : in.stable == HIGH;
}

// True when the debounced level CHANGED. Both rockers act on BOTH directions —
// which is the entire reason to use latching switches for the two settings you
// most need to feel the position of without looking.
bool settled(Input &in) {
  int now = digitalRead(in.pin);
  if (now != in.lastRead) { in.lastRead = now; in.changedAt = millis(); }
  if (now != in.stable && millis() - in.changedAt > DEBOUNCE_MS) {
    in.stable = now;
    return true;
  }
  return false;
}

/*
 * Every protocol line goes out BOTH transports, identically and in the same
 * order: LINK for the Pi, USB for the bench and for testing on a laptop with no
 * Raspberry Pi attached. One binary, two listeners, no build flag.
 *
 * On the USB path the ROM bootloader's 115200 log still arrives as garbage at
 * 9600 — receivers must discard unparseable lines (protocol §2.6.1).
 */
void emit(const char *fmt, ...) {
  char buf[MAX_LINE + 1];
  va_list ap;
  va_start(ap, fmt);
  vsnprintf(buf, sizeof buf, fmt, ap);
  va_end(ap);
  LINK.print(buf);
  Serial.print(buf);
}
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

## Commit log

2026-07-15 Implemented the Audio Feedback (TTS) module — replaced the stub with real speech output (espeak-ng), added zone hysteresis and detection priority in callbacks, and confirmed cooldown logic.
    [tts_worker.py]
2026-07-15 feat(vision-detection): add timer functionality for each id, implement 10 sec cooldown per object if class stays for too long in zone
2026-07-15 feat(vision-detection): add software-centered catch for head turning edge case
2026-07-22 feat(vision-detection): integrate obj det pipeline and callbacks to main.py thread instances
2026-09-30 feat: add barebones run pipeline script upon startup
    [BMI160.step, Left_Stem_Board.kicad_pcb, Left_Stem_Board_bom.csv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]
2026-10-15 docs: add additional guard rails
2026-10-18 snapshot: before fast track
2026-10-18 feat: add camera validation and tests
2026-11-11 docs(panel-revisions): session A YOLOv8 size comparison on the device
